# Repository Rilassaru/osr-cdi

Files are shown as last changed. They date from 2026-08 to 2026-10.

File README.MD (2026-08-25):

# OSR-CDI

Open-source programmable CDI (Capacitor Discharge Ignition) unit design and source repository for single-cylinder 2-stroke / 4-stroke motorcycles.

This repository includes complete design files for KiCad PCB layouts, PIC microcontroller firmware (MPLAB X), Windows-based map configuration utility "WinCDI" (Visual Studio), and baseline ignition map datasets.

---

## Directory Structure

```text
OSR-CDI/
|-- circuit/             # KiCad schematics, PCB layout, and manufacturing files (JLCPCB)
|   |-- KiCad_pcba/      # Main PCB board design and custom footprint library
|   `-- ...              # Variant circuits and legacy hardware designs
|-- firmware/            # PIC MCU firmware source code (MPLAB X IDE)
|-- wincdi/              # WinCDI map editing software source code (Visual Studio)
|   `-- lib/             # Pre-built static libraries and dependencies (FLTK, HIDAPI)
|-- genuine-map-files/   # Baseline and custom ignition curve maps (.bin / .hex / .csv)
`-- README.md

===========================================
Requirements & Toolchain
===========================================
   Circuit Design
      Tool: KiCad ver.10
      Notes: Custom footprints included in OSR-CDI_footprints.pretty

   Firmware
      Tool: MPLAB X IDE ver.6.2 & XC8 ver.2.5 Compiler
      Notes: Targets PIC16F1455 series microcontrollers

   Flashing / Debugging
      Tool: PICkit 3 / 4, MPLAB SNAP, MPLAB IPE
      Notes: Via on-board ICSP header pins

   GUI Utility (WinCDI)
      Tool: Visual Studio ver.2026 (C++ Desktop Development)
      Notes: Statically links against pre-built libraries in wincdi/lib/

===========================================
Getting Started
===========================================
1. Hardware Fabrication
   Ordering PCBs (e.g., JLCPCB):
      Production-ready Gerber ZIP archives, BOM (Bill of Materials) CSV files, and CPL placement CSV files are located in the circuit/KiCad_pcba/jlcpcb/ directory.

   Editing Schematics / Layout:
      Open the KiCad project files inside circuit/KiCad_pcba/. All custom footprints are bundled using relative paths.

2. Firmware Build & Flash
   1.Open the project under firmware/ using MPLAB X IDE.
   2.Select your target device (e.g., PIC16F1455) and XC8 compiler version, then run Clean and Build.
   3.Connect your programmer (PICkit / SNAP) to the ICSP header on the board and click Make and Program Device.

3. Building WinCDI (Windows Utility)
   1.Open the solution file (.sln) inside the wincdi/ directory with Visual Studio.
   2.Set configuration to Release (or Debug) and run Build Solution.
      Note: Required third-party libraries (FLTK, HIDAPI) are pre-configured in wincdi/lib/ for static linkage.

===========================================
Releases & Pre-built Packages
===========================================
If you only need ready-to-use binaries (WinCDI installers, compiled .hex firmware, and Gerber fabrication files), navigate to the [Releases] section on the right side of this repository.

===========================================
Disclaimer
===========================================
   Use this project, firmware, circuit schematics, and ignition map data entirely at your own risk.

   The authors, developers, and contributors assume no liability for any engine failure, vehicle damage, physical injury, electrical hazard, or any other damages resulting from the use of these materials.

   CDI circuits handle lethal high voltages and incorrect ignition timing can easily cause severe engine damage. Handle with care.

===========================================
License
===========================================
Project License
The core OSR-CDI design, firmware, and WinCDI utility code are released under the BSD 3-Clause License:

Copyright (c) OSR-CDI Project Contributors.
All rights reserved.

Redistribution and use in source and binary forms, with or without
modification, are permitted provided that the following conditions are met:

1. Redistributions of source code must retain the above copyright notice,
   this list of conditions and the following disclaimer.
2. Redistributions in binary form must reproduce the above copyright notice,
   this list of conditions and the following disclaimer in the documentation
   and/or other materials provided with the distribution.
3. Neither the name of the copyright holder nor the names of its
   contributors may be used to endorse or promote products derived from
   this software without specific prior written permission.

THIS SOFTWARE AND HARDWARE DESIGNS ARE PROVIDED BY THE COPYRIGHT HOLDERS AND
CONTRIBUTORS "AS IS" AND ANY EXPRESS OR IMPLIED WARRANTIES, INCLUDING, BUT NOT
LIMITED TO, THE IMPLIED WARRANTIES OF MERCHANTABILITY AND FITNESS FOR A
PARTICULAR PURPOSE ARE DISCLAIMED. IN NO EVENT SHALL THE COPYRIGHT HOLDER OR
CONTRIBUTORS BE LIABLE FOR ANY DIRECT, INDIRECT, INCIDENTAL, SPECIAL,
EXEMPLARY, OR CONSEQUENTIAL DAMAGES (INCLUDING, BUT NOT LIMITED TO,
PROCUREMENT OF SUBSTITUTE GOODS OR SERVICES; LOSS OF USE, DATA, OR PROFITS;
OR BUSINESS INTERRUPTION) HOWEVER CAUSED AND ON ANY THEORY OF LIABILITY,
WHETHER IN CONTRACT, STRICT LIABILITY, OR TORT (INCLUDING NEGLIGENCE OR
OTHERWISE) ARISING IN ANY WAY OUT OF THE USE OF THIS SOFTWARE, EVEN IF
ADVISED OF THE POSSIBILITY OF SUCH DAMAGE.

===========================================
Third-Party Libraries & Notices
===========================================
The wincdi/lib/ directory contains external binary dependencies used for building WinCDI. All rights belong to their respective copyright holders:

   FLTK (Fast Light Toolkit)
      License: GNU Library General Public License (LGPL) v2.0 with the FLTK Library Exception
      Website: https://www.fltk.org/
      The FLTK Library Exception explicitly permits static linking with applications without requiring the host application source code to be licensed under the LGPL.

   HIDAPI
      License: Multi-licensed (BSD-3-Clause / GPL v3 / HIDAPI License)
      Website: https://github.com/libusb/hidapi
   
   libpng / zlib / libjpeg
      License: zlib/libpng License / Independent JPEG Group License
      Included as static dependencies bundled with FLTK image routines.
   
   Microsoft Visual C++ 2010 Redistributable Component (msvcr100.dll)
      License: Microsoft Software License Terms

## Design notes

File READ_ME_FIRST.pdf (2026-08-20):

Please read first.

There is no warranty for all files, documents, and contents stated about the OSR - CDI you downloaded. No one will guarantee you at all.
There is no need to deal with everything at your own risk.
Only those who can correct mistakes themselves and return them to the community can use this file.
If you do not agree with this, you must immediately delete the downloaded file so that it does not invol ve anything at all.

はじめに必ずお読みください。

あなたがダウンロードしたOSR-CDIに関する全てのファイル、ドキュメント、記載した内容については一切の保証が ありません。
誰もあなたに一切保証してくれません。
全て自己責任で取り扱う必要がありません。
間違いはあなた自身が修正し、コミュニティに還元できる人だけが、このファイルを利用する事が出来ます。 これに同意できない人は、直ちにダウンロードしたファイルを削除して、今後一切関わらない様にしなければなりま せん。

请先阅读

所有关于您下载的OSR - CDI的所有文件，文档和内容均不作任何保证。 没有人会保证你的。
没有必要处理一切风险自负。
只有那些可以纠正错误并将其返回社区的人才可以使用此文件。 如果您不同意这一点，您必须立即删除下载的文件，使其完全不涉及任何内容。

처 음 에 반 드 시 읽 어 보 시 기 바 랍 니 다 .

당 신 이 다 운 로 드 한 OSR-CDI에 관 한 모 든 파 일 , 문 서 , 기 재 내 용 에 대 해 어 떠 한 보 증 도 하 지 않 습 니 다 . 아 무 도 당 신 에 게 보 증 해 주 지 않 습 니 다 .
모 두 자 기 책 임 으 로 취 급 할 필 요 가 없 습 니 다 .
실 수 는 자 신 이 수 정 하 고 지 역 사 회 에 환 원 할 수 있 는 사 람 만 이 이 파 일 을 사 용 할 수 있 습 니 다 .
이 에 동 의 하 지 않 는 사 람 은 즉 시 다 운 로 드 한 파 일 을 삭 제 하 고 향 후 일 절 관 계 않 도 록 해 야 합 니 다 .

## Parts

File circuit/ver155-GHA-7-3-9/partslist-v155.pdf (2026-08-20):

This is a reference only. Please select parts partly at your own risk. | 2026/2/8
OSR-CDI | Version1.5.x | * = common
Parts | Spec. | for | Pcs. | Comment | URL
PCB | Elecrow PCB | * | 1 | upload zip file to elecrow | https://www.elecrow.com/
PIC | PIC16F1455-I/P | * | 1 | PDIP | https://akizukidenshi.com/catalog/g/gI-10887/
Resist | 120 | * | 1 | carbon1/4W | https://akizukidenshi.com/catalog/g/g125121/
| 330 | * | 1 | carbon1/4W | https://akizukidenshi.com/catalog/g/gR-25331/
| 820 | * | 2 | carbon1/4W | https://akizukidenshi.com/catalog/g/gR-25821/
| 1.2K | * | 1 | carbon1/4W | https://akizukidenshi.com/catalog/g/gR-25122/
| 10K | * | 2 | carbon1/4W | https://akizukidenshi.com/catalog/g/gR-25103/
Cap. | 0.01uF50V | * | 2 | Ceramic capacitor 2.54pitch | https://akizukidenshi.com/catalog/g/gP-04063/
| 0.1uF50V | * | 3 | Ceramic capacitor 2.54pitch | https://akizukidenshi.com/catalog/g/gP-04065/
| 1uF50V | * | 3 | Ceramic capacitor 2.54pitch | https://akizukidenshi.com/catalog/g/gP-04066/
| 33uF50V | * | 2 | Electrolytic capacitor | https://www.sengoku.co.jp/mod/sgk_cart/detail.php?code=EEHD-0C3R
CDI cap. | 1.5uF400V | SDR200/DT200xx | 1 | UD40Y155K Film capacitor DC400V 1.5uF | https://www.sun-elle.com/eshopdo/refer/vid4009_42020.html
CDI cap. | 2.2uF400V | R1-Z/RZR/TZR | 1 | UD40Y225K Film capacitor DC400V 2.2uF | https://www.sun-elle.com/eshopdo/refer/vid4009_42030.html
CDI cap. | 1.5uF400V | RZV500R | 3 | UD40Y155K Film capacitor DC400V 1.5uF | https://www.sun-elle.com/eshopdo/refer/vid4009_42020.html
Diode | SD103A | * | 6 | Schottky diode for signal | https://akizukidenshi.com/catalog/g/gI-04271/
| UF2010 | R1-Z/RZR/RZV | 6 | Ultrafast Switching Rectifier | https://akizukidenshi.com/catalog/g/gI-00124/
| UF2010 | SDR200 | 7 | Ultrafast Switching Rectifier | https://akizukidenshi.com/catalog/g/gI-00124/
IC | 7805 regulator | * | 1 | Positive voltage regulator 100mA | https://akizukidenshi.com/catalog/g/gI-08973/
| DTC123EL | * | 1 | NPN Transistor with resistor | https://akizukidenshi.com/catalog/g/gI-12468/
| DTA123EL | * | 1 | PNP Transistor with resistor | https://akizukidenshi.com/catalog/g/gI-12465/
| TB6643KQ | * | 1 | Motor driver | https://akizukidenshi.com/catalog/g/gI-07688/
| 8P4SMA | * | 1 | Thyristor 400V 8A | https://akizukidenshi.com/catalog/g/gI-05001/
| TLP785 | * | 2 | photo coupler | https://akizukidenshi.com/catalog/g/gI-09846/
| | | | *TLP785 If you don't have any of the above, this is fine too | https://akizukidenshi.com/catalog/g/g107553/
| | | | *TLP785 If you don't have any of the above, this is fine too | https://akizukidenshi.com/catalog/g/g107554/
Others | Pin header | * | 1 | 40pin (use 5pin for PIC ICSP) | https://akizukidenshi.com/catalog/g/gC-00167/
| IC socket | * | 1 | 14pin | https://akizukidenshi.com/catalog/g/gP-00006/
| USB connector | * | 1 | miniB type female | https://akizukidenshi.com/catalog/g/gC-02235/
| Switch | * | 1 | on-off type | https://akizukidenshi.com/catalog/g/gP-03774/
| Tapping bis(3x5) | * | 1 | | https://akizukidenshi.com/catalog/g/gP-10254/
| Case | * | 1 | TAKACHI GHA7-3-9PB | https://www.sengoku.co.jp/mod/sgk_cart/detail.php?code=EEHD-0AL3
Cable | AVS-F 0.75sq x1m | SDR200 | 1 | Orange(橙)
| AVS-F 0.75sq x1m | SDR200 | 1 | White/Green(白/緑)
| AVS-F 0.75sq x1m | SDR200 | 1 | White/Black(白/黒)
| AVS-F 0.75sq x1m | SDR200 | 1 | Brown/Black(茶/黒)
| AVS-F 0.75sq x1m | SDR200 | 1 | Black/White(黒/白)
| AVS-F 0.75sq x1m | SDR200 | 1 | Yellow/Blue(黄/青)
| AVS-F 0.75sq x1m | SDR200 | 1 | Yellow(黄)
| AVS-F 0.75sq x1m | SDR200 | 1 | White/Red(白/赤)
| AVS-F 0.75sq x1m | SDR200 | 1 | Red/White(赤/白)
| AVS-F 0.75sq x1m | SDR200 | 2 | Black/Red(黒/赤)
| AVS-F 0.75sq x1m | SDR200 | 2 | Black(黒)
| AVS-F 0.75sq x1m | SDR200 | 1 | Brown(茶)
Cable | AVS-F 0.75sq x1m | R1-Z/RZR/RZV | 1 | Orange(橙)
| AVS-F 0.75sq x1m | R1-Z/RZR/RZV | 1 | White/Green(白/緑)
| AVS-F 0.75sq x1m | R1-Z/RZR/RZV | 1 | White/Black(白/黒)
| AVS-F 0.75sq x1m | R1-Z/RZR/RZV | 1 | Brown/Black(茶/黒)
| AVS-F 0.75sq x1m | R1-Z/RZR/RZV | 1 | Black/White(黒/白)
| AVS-F 0.75sq x1m | R1-Z/RZR/RZV | 1 | Yellow/Blue(黄/青)
| AVS-F 0.75sq x1m | R1-Z/RZR/RZV | 1 | Red/White(赤/白)
| AVS-F 0.75sq x1m | R1-Z/RZR/RZV | 1 | White/Red(白/赤)
| AVS-F 0.75sq x1m | R1-Z/RZR/RZV | 1 | Black/Red(黒/赤)
| AVS-F 0.75sq x1m | R1-Z/RZR/RZV | 1 | Red(赤)
| AVS-F 0.75sq x1m | R1-Z/RZR/RZV | 1 | Green(緑)
| AVS-F 0.75sq x1m | R1-Z/RZR/RZV | 2 | Black(黒)
| AVS-F 0.75sq x1m | R1-Z/RZR/RZV | 2 | Brown(茶)
Coupler | Coupler YPVS | R1-Z | 1 | 4P250 M | https://hi-1000.shop-pro.jp/ (http://hi-1000.shop-pro.jp/?pid=16134158)
| Coupler YPVS | R1-Z | 1 | 2P250 F | https://hi-1000.shop-pro.jp/ (http://hi-1000.shop-pro.jp/?pid=16134133)
| Coupler Pickup | R1-Z | 1 | 2極YPC防水M側コネクタ | https://hi-1000.shop-pro.jp/ (http://hi-1000.shop-pro.jp/?pid=26509217)
| Coupler others | R1-Z | 1 | 3極YPC防水F側コネクタ | https://hi-1000.shop-pro.jp/ (http://hi-1000.shop-pro.jp/?pid=26509264)
| Coupler Exciter | R1-Z | 1 | 3P110型オス端子側コネクタ | https://hi-1000.shop-pro.jp/ (http://hi-1000.shop-pro.jp/?pid=16046373)
| Coupler 2P110MRed | R1-Z | 1 | 2P110 M Red (for map switch) | https://hi-1000.shop-pro.jp/ (http://hi-1000.shop-pro.jp/?pid=86135216)
| Coupler 2P110FRed | R1-Z | 1 | 2P110 F Red (For map switch) | https://hi-1000.shop-pro.jp/ (http://hi-1000.shop-pro.jp/?pid=83037037)
Coupler | Coupler YPVS | RZR(29L) | 1 | 6P250 M | https://hi-1000.shop-pro.jp/ (http://hi-1000.shop-pro.jp/?pid=16134172)
| Coupler YPVS | RZR(29L) | 1 | 3P250 M | https://hi-1000.shop-pro.jp/ (http://hi-1000.shop-pro.jp/?pid=16134146)
| Coupler Pickup | RZR(29L) | 1 | YPC 2P M | https://hi-1000.shop-pro.jp/ (http://hi-1000.shop-pro.jp/?pid=48426715)
| Coupler others | RZR(29L) | 1 | YPC 4P F | https://hi-1000.shop-pro.jp/ (http://hi-1000.shop-pro.jp/?pid=56921534)
| Coupler Exciter | RZR(29L) | 1 | YPC 3P M | https://hi-1000.shop-pro.jp/ (http://hi-1000.shop-pro.jp/?pid=61793933)
| Coupler 2P110MRed | RZR(29L) | 1 | 2P110 M Red (for map switch) | https://hi-1000.shop-pro.jp/ (http://hi-1000.shop-pro.jp/?pid=86135216)
| Coupler 2P110FRed | RZR(29L) | 1 | 2P110 F Red (For map switch) | https://hi-1000.shop-pro.jp/ (http://hi-1000.shop-pro.jp/?pid=83037037)
Coupler | Coupler YPVS | RZV500R | 1 | YPC防水M8
| Coupler CDI | RZV500R | 1 | YPC防水F9
| Coupler 2P110MRed | RZV500R | 1 | 2P110 M Red (for map switch) | https://hi-1000.shop-pro.jp/ (http://hi-1000.shop-pro.jp/?pid=86135216)
| Coupler 2P110FRed | RZV500R | 1 | 2P110 F Red (For map switch) | https://hi-1000.shop-pro.jp/ (http://hi-1000.shop-pro.jp/?pid=83037037)
Grommet | NG-79-G | * | 1 | | https://www.monotaro.com/p/0933/3895/

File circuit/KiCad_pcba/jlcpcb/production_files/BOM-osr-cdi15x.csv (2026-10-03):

Comment | Designator | Footprint | LCSC | Quantity
1.2K | R2,R3,R5 | R_0603_1608Metric | C22765 | 3
100nF | C1,C10,C13,C14,C2,C3,C9 | C_0603_1608Metric | C14663 | 7
10K | R1,R9 | R_0603_1608Metric | C25804 | 2
10nF | C11,C6 | C_0603_1608Metric | C57112 | 2
120 | R6 | R_0603_1608Metric | C22787 | 1
1uF | C4,C7 | C_0603_1608Metric | C15849 | 2
330 | R13 | R_0603_1608Metric | C23138 | 1
330R(1/4W) | R10 | R_1206_3216Metric | C2907482 | 1
33uF | C5,C8 | CAP-SMD_BD6.3-L6.6-W6.6-FD-1 | C240518 | 2
470 | R4 | R_0603_1608Metric | C23179 | 1
5.1K | R7,R8 | R_0603_1608Metric | C23186 | 2
820R(1/4W) | R11,R12 | R_1206_3216Metric | C2974057 | 2
BT151 | Q2 | TO-252-2_L6.6-W6.1-P4.57-LS10.1-BR-CW | C2900856 | 1
CJ7805 | LDO1 | TO-252-2_L6.6-W6.1-P4.58-LS10.1-BR-CW | C21706 | 1
DTA123 | Q4 | SOT-23-3_L2.9-W1.3-P1.90-LS2.4-BR | C426848 | 1
DTC123 | Q1,Q3 | SOT-23-3_L2.9-W1.3-P1.90-LS2.4-BR | C406040 | 2
HC-TYPE-C-16P-01A | U2 | USB-C-SMD_HC-TYPE-C-16P-01A | C2894897 | 1
KT-0603R | LED1 | LED-SMD_L1.6-W0.8-R-RD | C2286 | 1
PIC16F1455-I/SL | U1 | PIC16F1455-SOIC-14_L8.7-W3.9-P1.27-LS6.0-BL | C640946 | 1
SD103AW | D1,D2,D3,D4,D5,D6 | SD103AW_SOD-123_L2.8-W1.8-LS3.7-RD | C181204 | 6
SS34_C8678 | D12 | SS34_SMA_L4.3-W2.6-LS5.2-RD | C8678 | 1
TB67H450FNG,EL | U5 | HSOP-8_L5.0-W4.0-P1.27-LS6.2-BL-EP | C545417 | 1
TLP785BL | U3,U4 | SOP-4_L6.5-W4.6-P2.54-LS10.0 | C2848507 | 2
US2M | D10,D11,D13,D7,D8,D9 | US2M_SMA_L4.4-W2.8-LS5.4-RD | C64958 | 6

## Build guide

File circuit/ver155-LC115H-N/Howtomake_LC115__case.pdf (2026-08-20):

おもて面で、最低限必要な実装範囲はこの赤枠の部分です

うら面で、最低限必要な実装範囲はこの赤枠の部分です

SDRのみ必要です

5

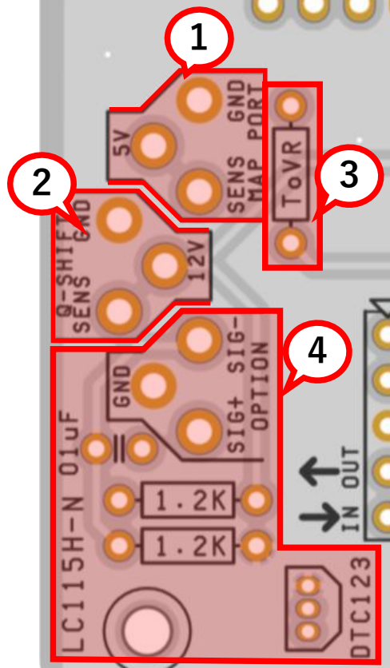
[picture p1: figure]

① マップ切り替えが必要な場合に必要
② クイックシフターを使う場合に必要
③ スロットルポジションセンサーを使う場合に必要
④ 点火シグナルを取り出す場合に必要
⑤ SDR用を制作する場合に必要

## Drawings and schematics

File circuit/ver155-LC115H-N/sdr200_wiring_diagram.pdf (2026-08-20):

## YAMAHA SDR Wiring color diagram w/OSR-CDI

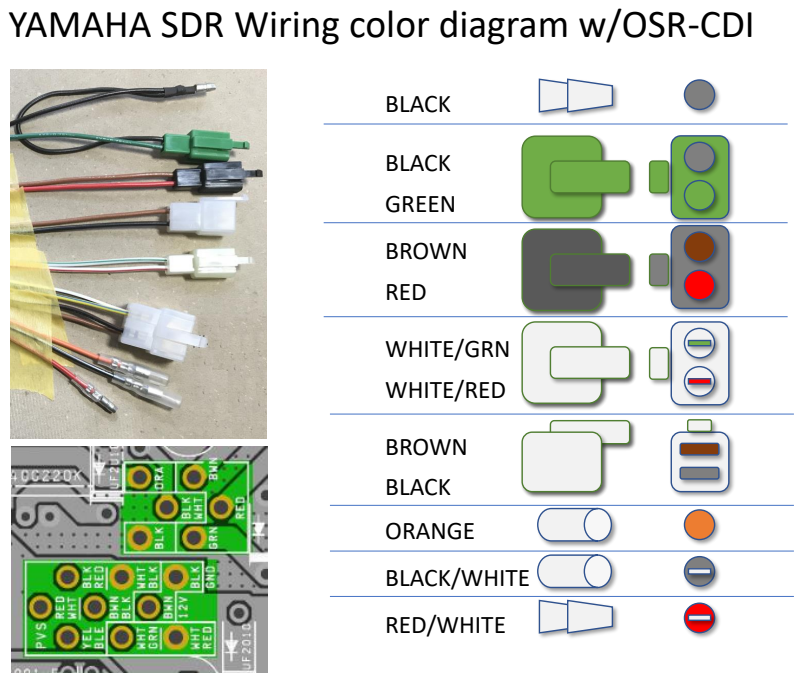
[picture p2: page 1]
BROWN; BLACK; WHITE/GRN; WHITE/RED; RED; GREEN; ORANGE; BLACK/WHITE; RED/WHITE

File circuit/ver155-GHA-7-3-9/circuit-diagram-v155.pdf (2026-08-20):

OSR CDIv1.5.5 2026/02/08 Rilassaru + Mass.Matt.

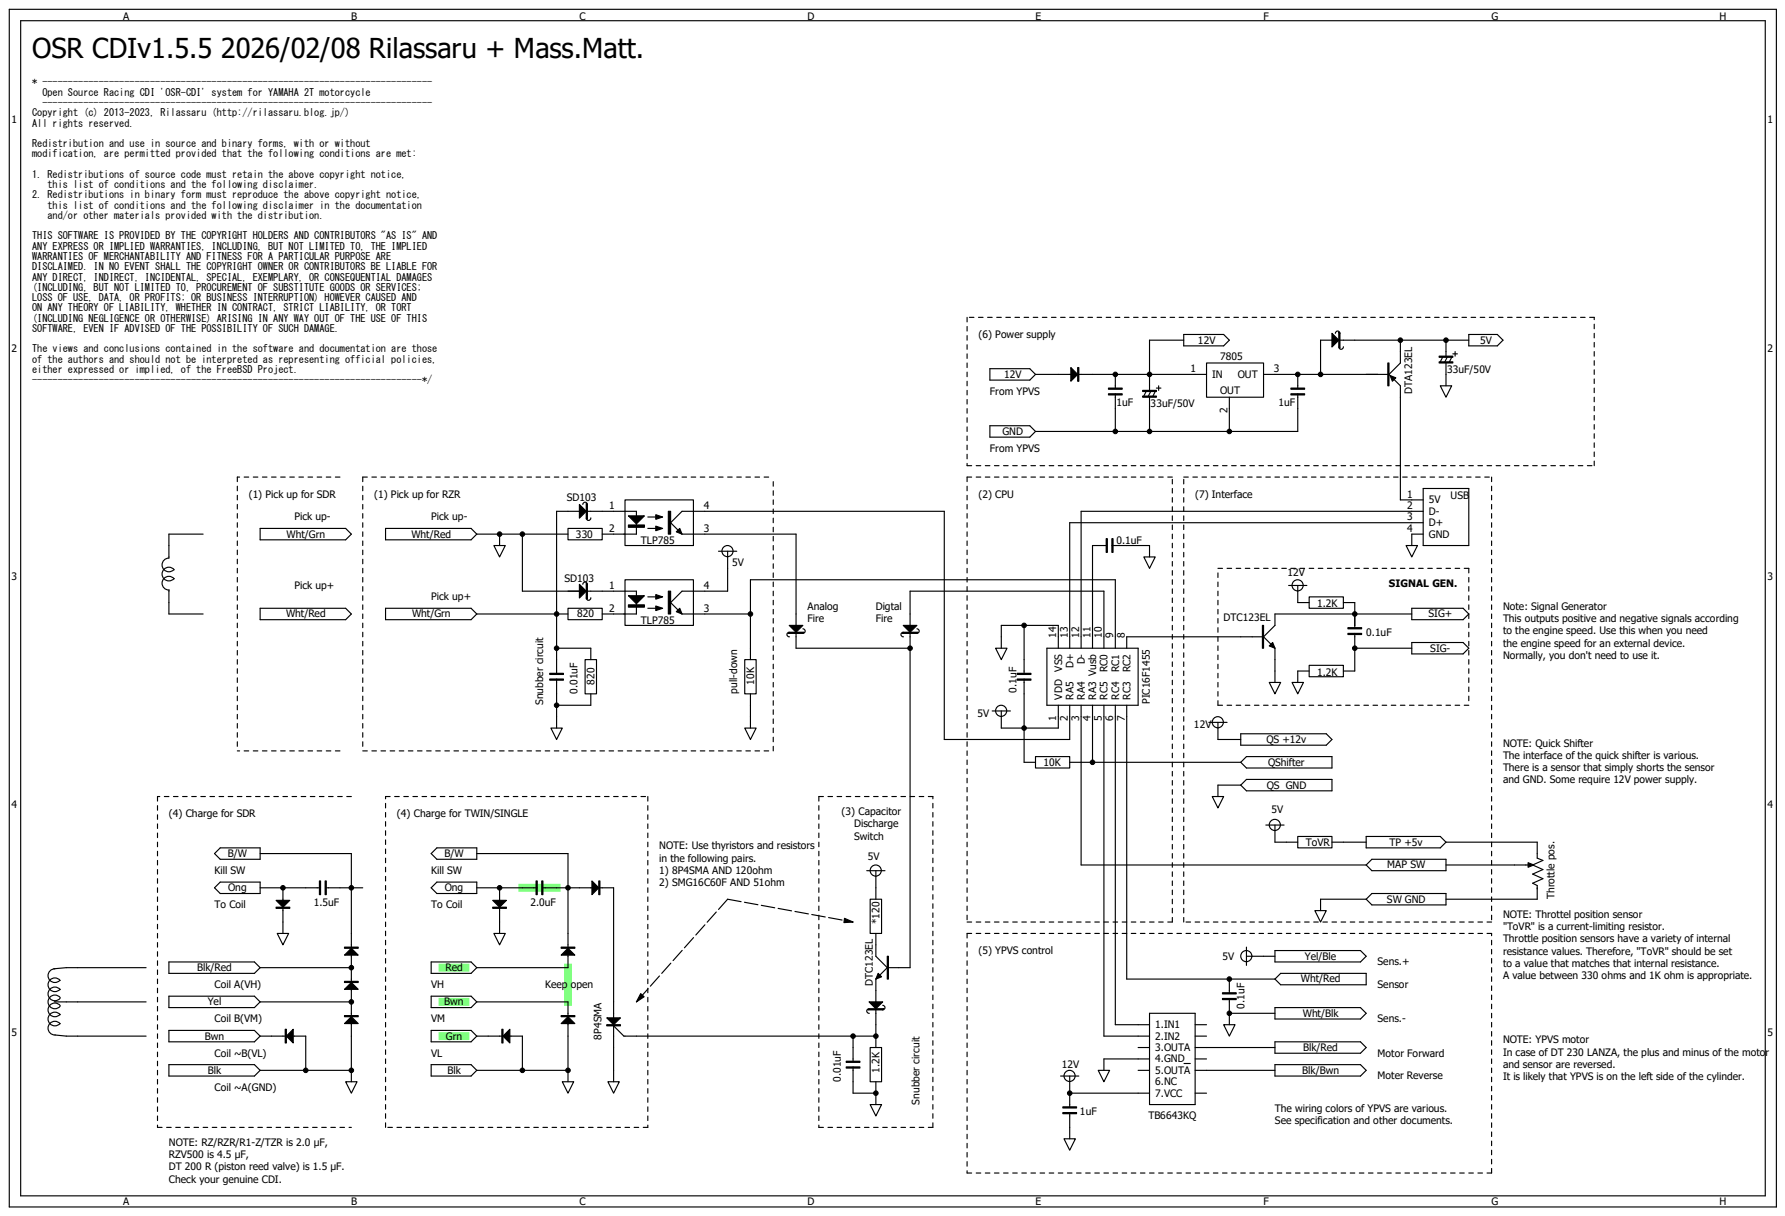
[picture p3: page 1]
(3) Capacitor Discharge Switch; Analog Fire; Digtal Fire; SIGNAL GEN.; TLP785; 12V VDD; 1 VSS 14 RC4; 5 Vusb 11 RA3; 4 D+ 13 D- 12 PIC16F1455; 1.IN1 2.IN2 3.OUTA 4.GND; 7.VCC; 5.OUTA; 5V ⁸²⁰; Throttle pos.; ToVR 0.1uF 0.1uF; DTC123EL; OUT; DTA¹²³EL; 33uF/50V 8P4SMA; Pick up-; Pick up+; Wht/Red; Wht/Grn; (1) Pick up for SDR; (1) Pick up for RZR; From YPVS; GND; QShifter; Blk/Bwn; Blk/Red; Yel/Ble; Sensor; Sens.-; Sens.+; Wht/Blk; Motor Forward; Moter Reverse; QS GND; Kill SW; To Coil; Ong; Grn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

Open Source Racing CDI 'OSR-CDI' system for YAMAHA 2T motorcycle
Copyright (c) 2013-2023, Rilassaru (http://rilassaru.blog.jp/)
All rights reserved.

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

1. Redistributions of source code must retain the above copyright notice,
this list of conditions and the following disclaimer.
2. Redistributions in binary form must reproduce the above copyright notice,
this list of conditions and the following disclaimer in the documentation
and/or other materials provided with the distribution.

THIS SOFTWARE IS PROVIDED BY THE COPYRIGHT HOLDERS AND CONTRIBUTORS "AS IS" AND
ANY EXPRESS OR IMPLIED WARRANTIES, INCLUDING, BUT NOT LIMITED TO, THE IMPLIED
WARRANTIES OF MERCHANTABILITY AND FITNESS FOR A PARTICULAR PURPOSE ARE
DISCLAIMED. IN NO EVENT SHALL THE COPYRIGHT OWNER OR CONTRIBUTORS BE LIABLE FOR
ANY DIRECT, INDIRECT, INCIDENTAL, SPECIAL, EXEMPLARY, OR CONSEQUENTIAL DAMAGES
(INCLUDING, BUT NOT LIMITED TO, PROCUREMENT OF SUBSTITUTE GOODS OR SERVICES;
LOSS OF USE, DATA, OR PROFITS; OR BUSINESS INTERRUPTION) HOWEVER CAUSED AND
ON ANY THEORY OF LIABILITY, WHETHER IN CONTRACT, STRICT LIABILITY, OR TORT
(INCLUDING NEGLIGENCE OR OTHERWISE) ARISING IN ANY WAY OUT OF THE USE OF THIS
SOFTWARE, EVEN IF ADVISED OF THE POSSIBILITY OF SUCH DAMAGE.
The views and conclusions contained in the software and documentation are those
of the authors and should not be interpreted as representing official policies,
either expressed or implied, of the FreeBSD Project.

USB Snubber circuit

D+ 3
GND 4

Note: Signal Generator
This outputs positive and negative signals according
to the engine speed. Use this when you need
the engine speed for an external device.
Normally, you don't need to use it.

MAP SW pull-down Snubber circuit

NOTE: Quick Shifter
The interface of the quick shifter is various.
There is a sensor that simply shorts the sensor
and GND. Some require 12V power supply.

NOTE: Use thyristors and resistors
in the following pairs.
1) 8P4SMA AND 120ohm
2) SMG16C60F AND 51ohm

NOTE: Throttel position sensor
"ToVR" is a current-limiting resistor.
Throttle position sensors have a variety of internal
resistance values. Therefore, "ToVR" should be set
to a value that matches that internal resistance.
A value between 330 ohms and 1K ohm is appropriate.

NOTE: YPVS motor
In case of DT 230 LANZA, the plus and minus of the motor
and sensor are reversed.
It is likely that YPVS is on the left side of the cylinder.

The wiring colors of YPVS are various.
See specification and other documents.

NOTE: RZ/RZR/R1-Z/TZR is 2.0 μF,
RZV500 is 4.5 μF,
DT 200 R (piston reed valve) is 1.5 μF.
Check your genuine CDI.

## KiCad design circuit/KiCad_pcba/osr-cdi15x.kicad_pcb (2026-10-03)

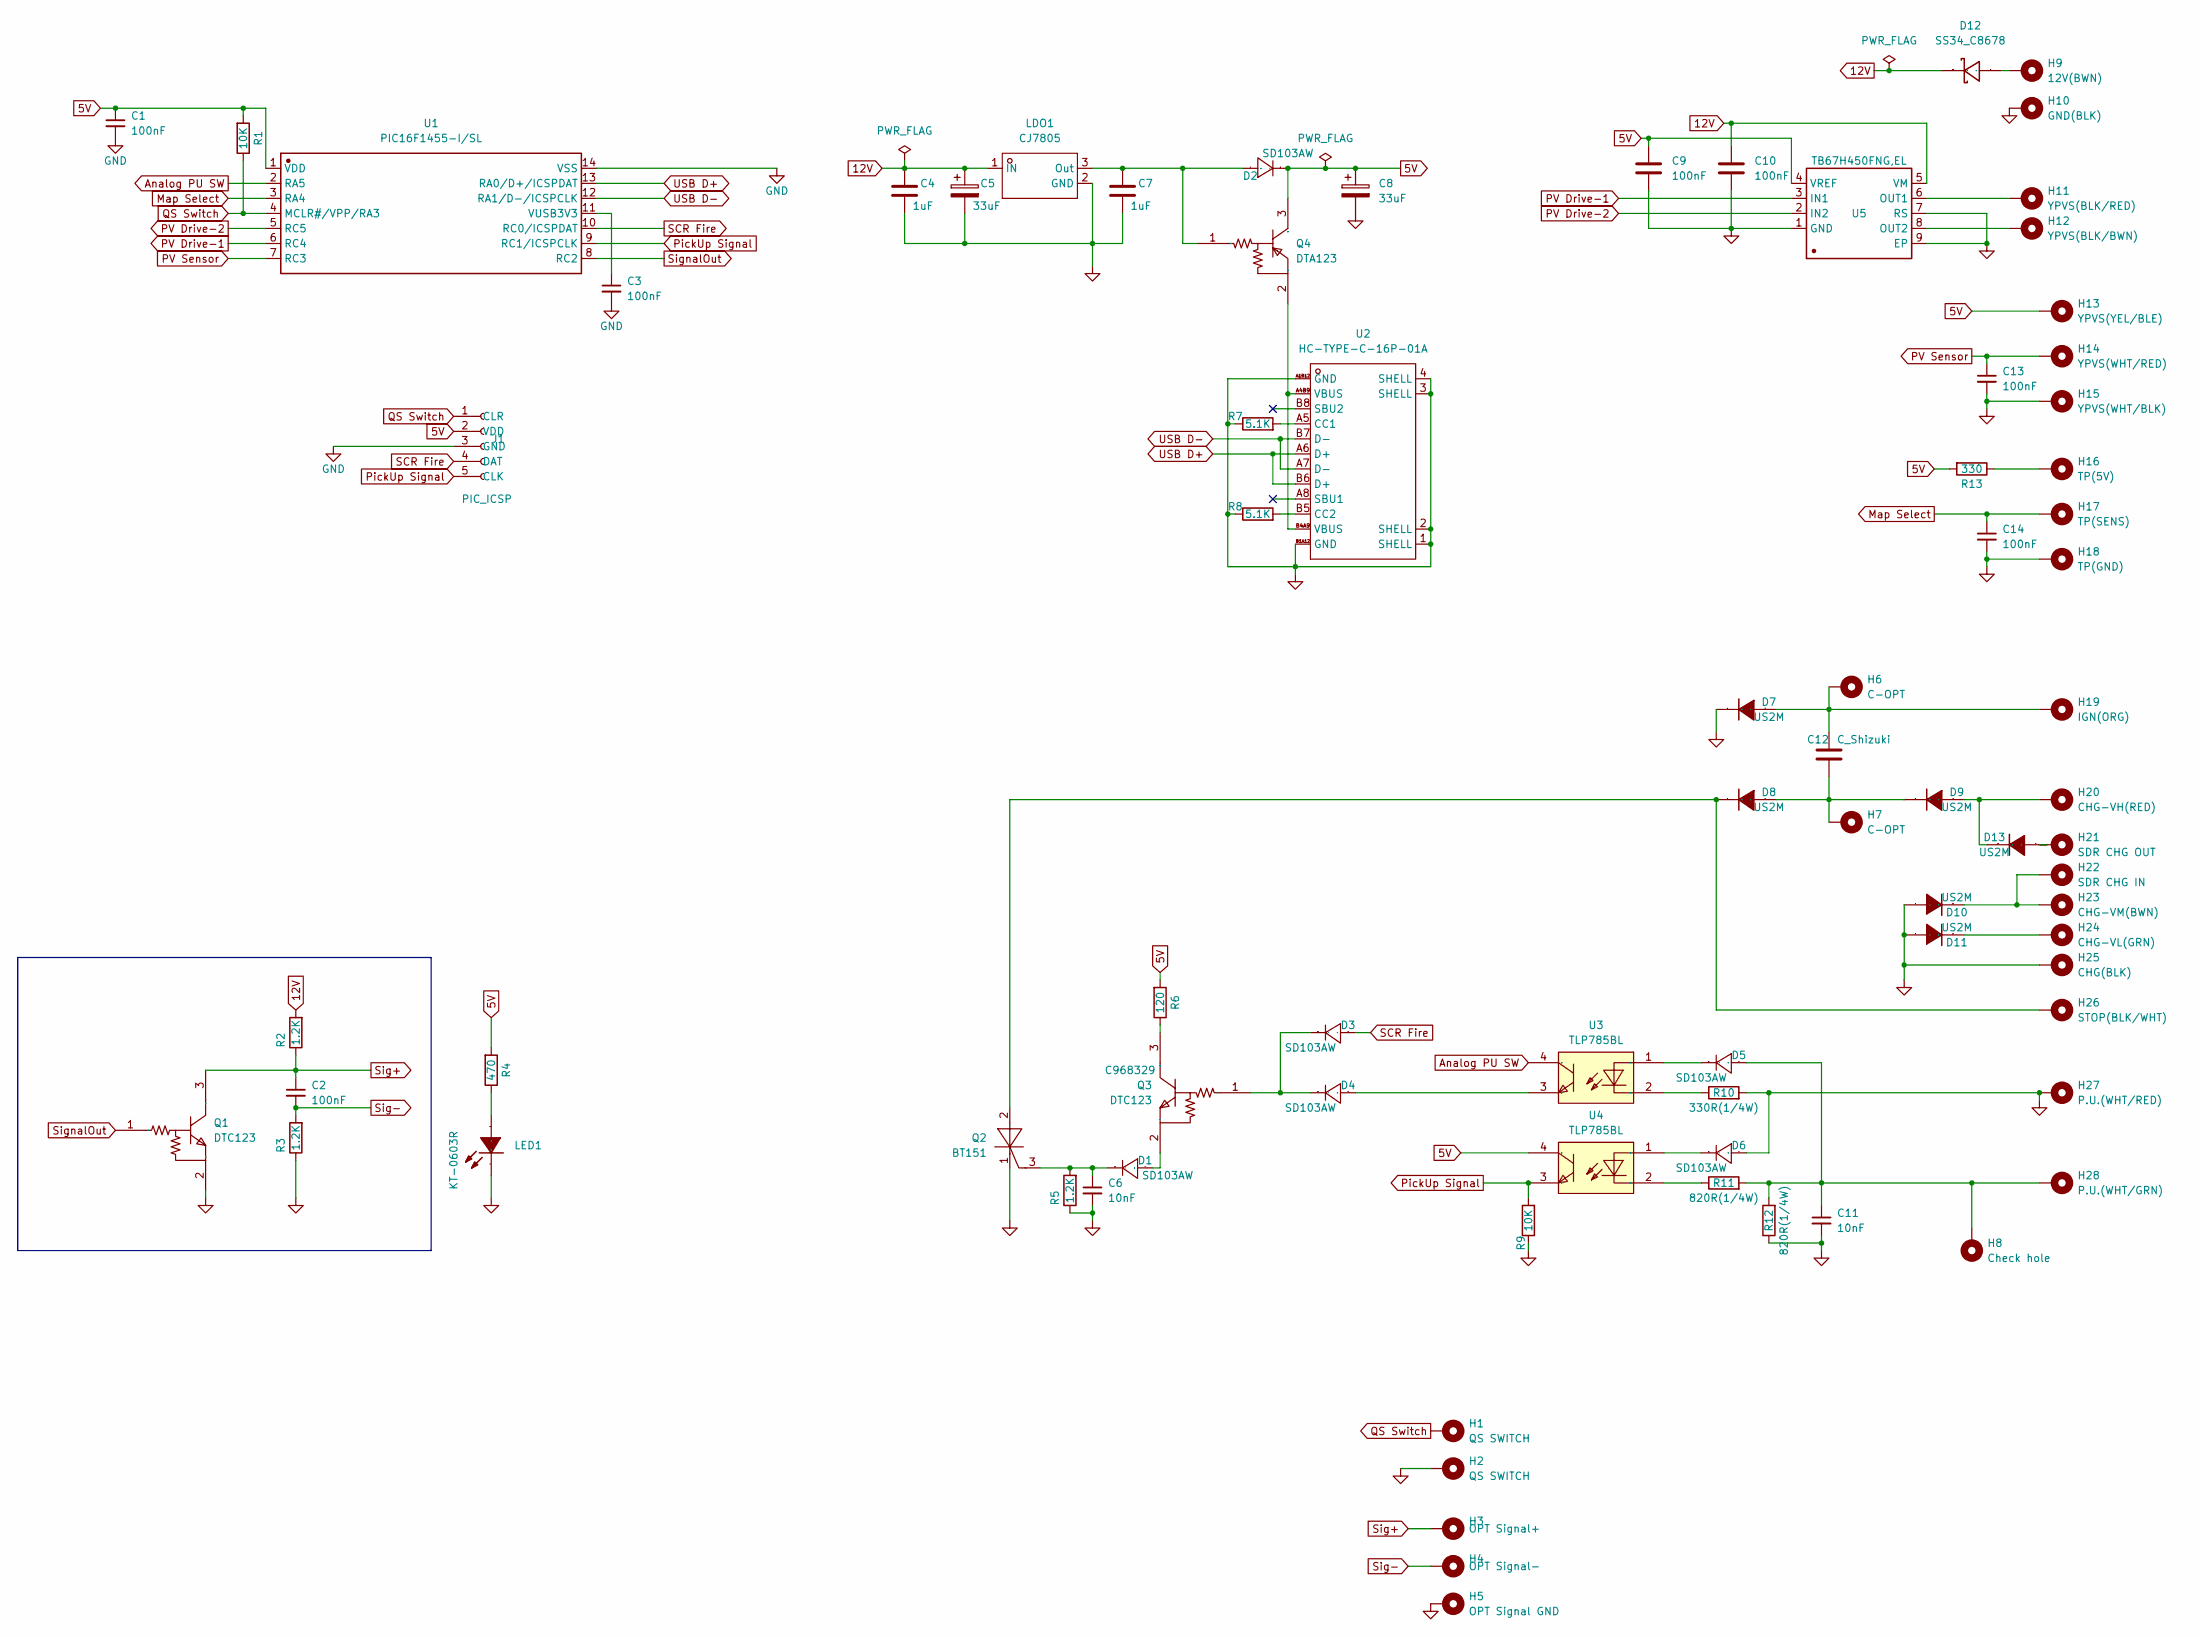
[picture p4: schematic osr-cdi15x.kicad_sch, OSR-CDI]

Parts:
C1, C2, C3, C9, C10, C13, C14: 100nF; C_0603_1608Metric
C4, C7: 1uF; C_0603_1608Metric
C5, C8: 33uF; CAP-SMD_BD6.3-L6.6-W6.6-FD-1
C6, C11: 10nF; C_0603_1608Metric
C12: C_Shizuki; Capacitor_Sizuki400V
D1, D2, D3, D4, D5, D6: SD103AW; SD103AW_SOD-123_L2.8-W1.8-LS3.7-RD; JLC_3DModel_Q 560a7cf99d0e44cb9af362aaf5d7923d
D7, D8, D9, D10, D11, D13: US2M; US2M_SMA_L4.4-W2.8-LS5.4-RD; Manufacturer Part US2M
D12: SS34_C8678; SS34_SMA_L4.3-W2.6-LS5.2-RD; Manufacturer Part SS34
H1, H2: QS SWITCH; M_Hole_2.5mm_Pad_075Wire
H3: OPT Signal+; M_Hole_2.5mm_Pad_075Wire
H4: OPT Signal-; M_Hole_2.5mm_Pad_075Wire
H5: OPT Signal GND; M_Hole_2.5mm_Pad_075Wire
H6, H7: C-OPT; M_Hole_2.5mm_Pad_075Wire
H8: Check hole; M_Hole_1.6-0.9mm_Pad
H9: 12V(BWN); M_Hole_2.5mm_Pad_075Wire
H10: GND(BLK); M_Hole_2.5mm_Pad_075Wire
H11: YPVS(BLK/RED); M_Hole_2.5mm_Pad_075Wire
H12: YPVS(BLK/BWN); M_Hole_2.5mm_Pad_075Wire
H13: YPVS(YEL/BLE); M_Hole_2.5mm_Pad_075Wire
H14: YPVS(WHT/RED); M_Hole_2.5mm_Pad_075Wire
H15: YPVS(WHT/BLK); M_Hole_2.5mm_Pad_075Wire
H16: TP(5V); M_Hole_2.5mm_Pad_075Wire
H17: TP(SENS); M_Hole_2.5mm_Pad_075Wire
H18: TP(GND); M_Hole_2.5mm_Pad_075Wire
H19: IGN(ORG); M_Hole_2.5mm_Pad_075Wire
H20: CHG-VH(RED); M_Hole_2.5mm_Pad_075Wire
H21: SDR CHG OUT; M_SQ_Hole_2.5mm_Pad_075Wire
H22: SDR CHG IN; M_SQ_Hole_2.5mm_Pad_075Wire
H23: CHG-VM(BWN); M_Hole_2.5mm_Pad_075Wire
H24: CHG-VL(GRN); M_Hole_2.5mm_Pad_075Wire
H25: CHG(BLK); M_Hole_2.5mm_Pad_075Wire
H26: STOP(BLK/WHT); M_Hole_2.5mm_Pad_075Wire
H27: P.U.(WHT/RED); M_Hole_2.5mm_Pad_075Wire
H28: P.U.(WHT/GRN); M_Hole_2.5mm_Pad_075Wire
J1: PIC_ICSP; ICSP_5PIN
LDO1: CJ7805; TO-252-2_L6.6-W6.1-P4.58-LS10.1-BR-CW; Manufacturer Part CJ7805 3%; LCSC Part Name 5V 1.5A 35V
LED1: KT-0603R; LED-SMD_L1.6-W0.8-R-RD; Manufacturer Part KT-0603R
Q1, Q3: DTC123; SOT-23-3_L2.9-W1.3-P1.90-LS2.4-BR; Manufacturer Part DTC123JCA; LCSC Part Name 数字晶体管（内置电阻）
Q2: BT151; TO-252-2_L6.6-W6.1-P4.57-LS10.1-BR-CW; Manufacturer Part BT151; LCSC Part Name BT151
Q4: DTA123; SOT-23-3_L2.9-W1.3-P1.90-LS2.4-BR; Manufacturer Part DTA123JCA; LCSC Part Name 数字晶体管（内置电阻）
R1, R9: 10K; R_0603_1608Metric
R2, R3, R5: 1.2K; R_0603_1608Metric
R4: 470; R_0603_1608Metric
R6: 120; R_0603_1608Metric
R7, R8: 5.1K; R_0603_1608Metric
R10: 330R(1/4W); R_1206_3216Metric
R11, R12: 820R(1/4W); R_1206_3216Metric
R13: 330; R_0603_1608Metric
U1: PIC16F1455-I/SL; PIC16F1455-SOIC-14_L8.7-W3.9-P1.27-LS6.0-BL; Manufacturer Part PIC16F1455-I/SL
U2: HC-TYPE-C-16P-01A; USB-C-SMD_HC-TYPE-C-16P-01A; Manufacturer Part HC-TYPE-C-16P-01A; LCSC Part Name Type-C 母 卧贴
U3, U4: TLP785BL; SOP-4_L6.5-W4.6-P2.54-LS10.0; Manufacturer Part TLP785(BL-TP6,F; LCSC Part Name 光电耦合器，红外发光二极管与光电晶体管
U5: TB67H450FNG,EL; HSOP-8_L5.0-W4.0-P1.27-LS6.2-BL-EP; Manufacturer Part TB67H450FNG,EL

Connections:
5V: C1.1, C8.1, C9.1, D2.1 (C), H13.1 (1_1), J1.2 (VDD), Q4.3 (OUT), R1.2, R4.2, R6.2, R13.2, U1.1 (VDD), U4.4 (COL), U5.4 (VREF)
12V: C4.1, C5.1, C10.1, D12.1 (K), LDO1.1 (IN), R2.2, U5.5 (VM)
Analog PU SW: U1.2 (RA5), U3.4 (COL)
GND: C1.2, C3.2, C4.2, C5.2, C6.2, C7.2, C8.2, C9.2, C10.2, C11.2, C13.2, C14.2, D6.2 (A), D7.1 (K), D10.2 (A), D11.2 (A), H2.1 (1_1), H5.1 (1_1), H10.1 (1_1), H15.1 (1_1), H18.1 (1_1), H25.1 (1_1), H27.1 (1_1), J1.3 (GND), LDO1.2 (GND), LED1.2 (K), Q1.2 (GND), Q2.1 (K), R3.1, R5.1, R7.1, R8.1, R9.1, R10.2, R12.1, U1.14 (VSS), U2.1 (SHELL), U2.2 (SHELL), U2.3 (SHELL), U2.4 (SHELL), U2.A1B12 (GND), U2.B1A12 (GND), U5.1 (GND), U5.7 (RS), U5.9 (EP)
Map Select: C14.1, H17.1 (1_1), U1.3 (RA4)
unnamed: D1.2 (A), Q3.2 (GND)
unnamed: C6.1, D1.1 (C), Q2.3 (G), R5.2
unnamed: C7.1, D2.2 (A), LDO1.3 (Out), Q4.1 (IN)
unnamed: D3.1 (C), D4.1 (C), Q3.1 (IN)
unnamed: D4.2 (A), U3.3 (EMI)
unnamed: C11.1, D5.2 (A), H8.1 (1_1), H28.1 (1_1), R11.2, R12.2
unnamed: D5.1 (C), U3.1 (AN)
unnamed: D6.1 (C), U4.1 (AN)
unnamed: C12.2, D7.2 (A), H6.1 (1_1), H19.1 (1_1)
unnamed: C12.1, D8.2 (A), D9.1 (K), H7.1 (1_1)
unnamed: D8.1 (K), H26.1 (1_1), Q2.2 (A)
unnamed: D10.1 (K), H22.1 (1_1), H23.1 (1_1)
unnamed: D11.1 (K), H24.1 (1_1)
unnamed: D12.2 (A), H9.1 (1_1)
unnamed: D13.2 (A), H21.1 (1_1)
unnamed: D9.2 (A), D13.1 (K), H20.1 (1_1)
unnamed: H16.1 (1_1), R13.1
unnamed: LED1.1 (A), R4.1
unnamed: Q3.3 (OUT), R6.1
unnamed: Q4.2 (GND), U2.A4B9 (VBUS), U2.B4A9 (VBUS)
unnamed: C3.1, U1.11 (VUSB3V3)
unnamed: R7.2, U2.A5 (CC1)
unnamed: R8.2, U2.B5 (CC2)
unnamed: R10.1, U3.2 (CAT)
unnamed: R11.1, U4.2 (CAT)
unnamed: H11.1 (1_1), U5.6 (OUT1)
unnamed: H12.1 (1_1), U5.8 (OUT2)
PV Drive-1: U1.6 (RC4), U5.3 (IN1)
PV Drive-2: U1.5 (RC5), U5.2 (IN2)
PV Sensor: C13.1, H14.1 (1_1), U1.7 (RC3)
PickUp Signal: J1.5 (CLK), R9.2, U1.9 (RC1/ICSPCLK), U4.3 (EMI)
QS Switch: H1.1 (1_1), J1.1 (CLR), R1.1, U1.4 (MCLR#/VPP/RA3)
SCR Fire: D3.2 (A), J1.4 (DAT), U1.10 (RC0/ICSPDAT)
Sig+: C2.1, H3.1 (1_1), Q1.3 (OUT), R2.1
Sig-: C2.2, H4.1 (1_1), R3.2
SignalOut: Q1.1 (IN), U1.8 (RC2)
USB D+: U1.13 (RA0/D+/ICSPDAT), U2.A6 (D+), U2.B6 (D+)
USB D-: U1.12 (RA1/D-/ICSPCLK), U2.A7 (D-), U2.B7 (D-)

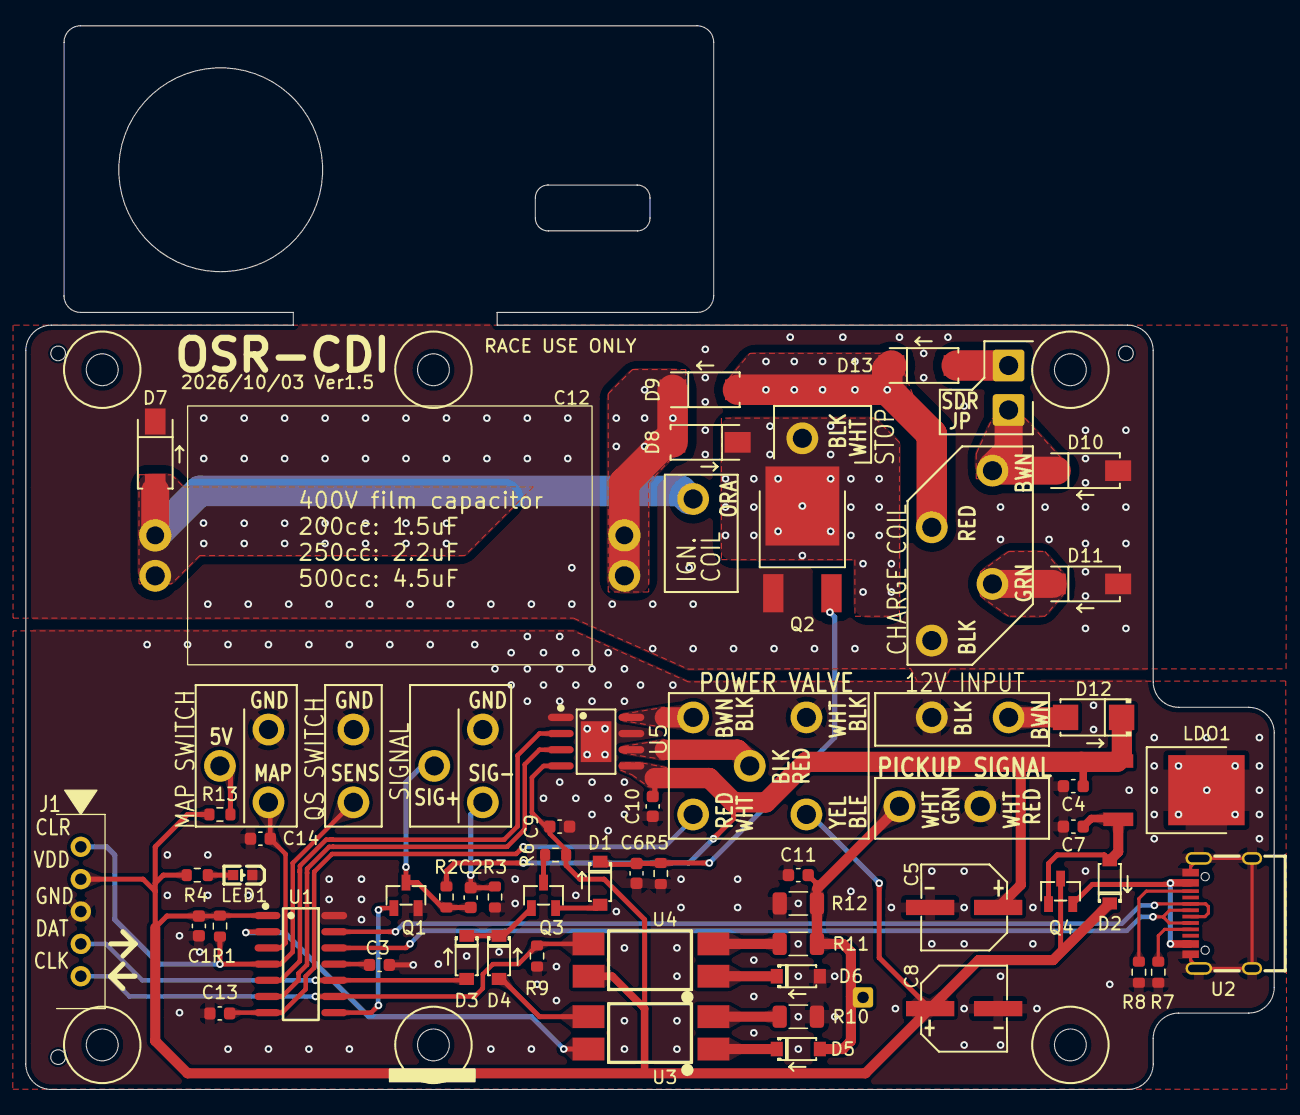
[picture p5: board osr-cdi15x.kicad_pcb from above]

Board: 2 copper layers, 98.0 x 83.5 mm, 80 parts (0 on the bottom side), 43 nets.

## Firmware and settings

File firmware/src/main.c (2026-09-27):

/* ----------------------------------------------------------------------------
  Open Source Replica CDI 'OSR-CDI' system for YAMAHA 2T motorcycle
  ----------------------------------------------------------------------------
Copyright(c) 2013-, Rilassaru(http://rilassaru.blog.jp/)
All rights reserved.

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
1. Redistributions of source code must retain the above copyright notice,
   this list of conditions and the following disclaimer. 
2. Redistributions in binary form must reproduce the above copyright notice,
   this list of conditions and the following disclaimer in the documentation
   and/or other materials provided with the distribution. 

THIS SOFTWARE IS PROVIDED BY THE COPYRIGHT HOLDERS AND CONTRIBUTORS "AS IS" AND
ANY EXPRESS OR IMPLIED WARRANTIES, INCLUDING, BUT NOT LIMITED TO, THE IMPLIED
WARRANTIES OF MERCHANTABILITY AND FITNESS FOR A PARTICULAR PURPOSE ARE
DISCLAIMED. IN NO EVENT SHALL THE COPYRIGHT OWNER OR CONTRIBUTORS BE LIABLE FOR
ANY DIRECT, INDIRECT, INCIDENTAL, SPECIAL, EXEMPLARY, OR CONSEQUENTIAL DAMAGES
(INCLUDING, BUT NOT LIMITED TO, PROCUREMENT OF SUBSTITUTE GOODS OR SERVICES;
LOSS OF USE, DATA, OR PROFITS; OR BUSINESS INTERRUPTION) HOWEVER CAUSED AND
ON ANY THEORY OF LIABILITY, WHETHER IN CONTRACT, STRICT LIABILITY, OR TORT
(INCLUDING NEGLIGENCE OR OTHERWISE) ARISING IN ANY WAY OUT OF THE USE OF THIS
SOFTWARE, EVEN IF ADVISED OF THE POSSIBILITY OF SUCH DAMAGE.

The views and conclusions contained in the software and documentation are those
of the authors and should not be interpreted as representing official policies, 
either expressed or implied, of the FreeBSD Project.
----------------------------------------------------------------------------*/
/* Updates
DATE        VERSION UPDATE
01/NOV/2015 2.2.0   RCDI PIC16F1455 version released.
10/OCT/2016 2.3.0a  Solenid driver added.
26/OCT/2016 2.3.0b  Rev limitter added.
18/FEB/2017 2.3.1   Release.
04/MAY/2017 2.3.2   For RZ250R(29L), Moved the division processing into timer2 routine.
04/JUN/2017 2.3.3   Fixed for both Single and Twin specification.
-----------------
-- A product named RCDI existed in the past, so the name was changed to OSR-CDI.
-----------------
08/AUG/2017 1.0.1   OSR-CDI version beta
01/JAN/2018 1.0.4   Minor bug fix, final release
-----------------
11/MAR/2018 1.1.0   2nd P.U. signal supplessed for DT200/TZR125/RZ125
15/APL/2018 1.1.1   2nd P.U. signal enabler for DT200/TZR125/RZ125
12/MAR/2018 1.1.2   Changeable PV value to fit DT230 LANZA
-----------------
16/JUN/2018 1.2.0   Fixed some bugs and final release
17/OCT/2019 1.2.1   Plus wave pick up singal enable timing was changed.
-----------------
05/JUN/2019 1.3.0   The control of INTF was changed in order to avoid the noise
                    at the time of spark.
15/AUG/2019 1.3.0b  Thyristor gate time changed.
-----------------
14/NOV/2020 1.4.0a  Extended the ignition refusal time using Timer0.
                    Changed the behavior of Quick Shifter. 
27/Feb/2021 1.4.0b  Suppresses ignition when the first positive wave arrives.
03/JUN/2022 1.4.0c  Fix do not stop with 'use quick shifter as stop switch'.
-----------------
06/JUN/2023 1.5.0   New version released. Supports 4 maps.
26/JUL/2023 1.5.1   Changed analog ignition mechanism.
                    Changed the scanning method for maximum and minimum values
                    in the initial operation of PVS.
25/JUL/2023 1.5.2   Analog ignition control has been revised to improve starting
                    performance.
27/JUL/2023         Fixed a bug in PV control associated with 4ch.
29/SEP/2024 1.5.3   Added option to maintain analog ignition below a certain rotation speed.
10/Feb/2025 1.5.4a  The on time of the thyristor gate is made variable.
03/Mar/2025 1.5.4b  When the analog ignition count is set to 0,
                    analog ignition is not actually performed.
08/Feb/2026 1.5.5   Minor bug-fix.
12/Aug/2026 1.5.6a  PVS Added a fully closed state to the initial operation of the PVS.
                    *The version has been updated to include a PCBA case for the circuit board assembly.
06/Oct/2026 1.5.6b  USB userinterface modified UserID/DevID/RevID
26/Oct/2026 1.5.6c  XC8 Ver. 4.0 (C99) compliance and source file modularization/organization
-----------------

Version a.b.c
        | | +Minor version up with only software change
        | +--Minor version up with hardware change
        +----Major version up
*/

// CONFIG1
#pragma config FOSC = INTOSC    // Oscillator Selection Bits (INTOSC oscillator: I/O function on CLKIN pin)
#pragma config WDTE = ON        // Watchdog Timer Enable (WDT disabled)
#pragma config PWRTE = ON       // Power-up Timer Enable (PWRT enabled)
#pragma config MCLRE = OFF      // MCLR Pin Function Select (MCLR/VPP pin function is digital input)
#pragma config CP = OFF         // Flash Program Memory Code Protection (Program memory code protection is disabled)
#pragma config BOREN = ON       // Brown-out Reset Enable (Brown-out Reset enabled)
#pragma config CLKOUTEN = OFF   // Clock Out Enable (CLKOUT function is disabled. I/O or oscillator function on the CLKOUT pin)
#pragma config IESO = OFF       // Internal/External Switchover Mode (Internal/External Switchover Mode is disabled)
#pragma config FCMEN = OFF      // Fail-Safe Clock Monitor Enable (Fail-Safe Clock Monitor is disabled)

// CONFIG2
#pragma config USBLSCLK = 48MHz // USB Low SPeed Clock Selection bit (System clock expects 48 MHz, FS/LS USB CLKENs divide-by is set to 8.)
#pragma config WRT = OFF        // Flash Memory Self-Write Protection (Write protection off)
#pragma config CPUDIV = CLKDIV3 // CPU System Clock Selection Bit (CPU system clock divided by 3)
#pragma config PLLMULT = 3x     // PLL Multipler Selection Bit (3x Output Frequency Selected)
#pragma config PLLEN = ENABLED  // PLL Enable Bit (3x or 4x PLL Enabled)
#pragma config STVREN = ON      // Stack Overflow/Underflow Reset Enable (Stack Overflow or Underflow will cause a Reset)
#pragma config BORV = LO        // Brown-out Reset Voltage Selection (Brown-out Reset Voltage (Vbor), low trip point selected.)
#pragma config LPBOR = OFF      // Low-Power Brown Out Reset (Low-Power BOR is disabled)
#pragma config LVP = OFF        // Low-Voltage Programming Enable (High-voltage on MCLR/VPP must be used for programming)

#include "HardwareProfile.h"
#include "osr_cdi.h"
#include "usb.h"

//------------------------------------------------------------------
//prototype
//------------------------------------------------------------------
void main(void);
void initialize_system(void);
void __interrupt() ISRCode(void);
uint8_t common_analog_digtal_conv8(uint8_t ch);

/** -----------------------------------------------------------------
 * global variable
------------------------------------------------------------------ */
volatile uint8_t	gRPM = 0;	
volatile uint8_t	gEngineState = ENGINE_STATE_STOPPED;
volatile uint8_t    gMapSelect = 0;
volatile uint8_t	gQShifterState = 0;
volatile uint8_t	gQShifterCount = 0;

/**
 * @brief Initializes the firmware and runs the foreground control loop.
 *
 * Enables interrupts, services USB/HID, updates the PVS and map selection,
 * and refreshes the status data reported to the host.
 */
void main(void) {
    uint16_t ii;
    uint8_t anresult;
    initialize_system();
    initialize_pvs_min_max();

    gpioANALOG_PU_ENABLER = ENABLE_2ND_WAVE_IGNITION;

    // Initialize interrupt setting
    INTE    = 1;		// Generic Interrupt on
    INTEDG  = 1;		// Interrupt on rising edge of INT pin
    TMR1IE  = 1;		// Timer1 interrupt on
    TMR2IE  = 1;		// Timer2 interrupt on
    TMR1ON  = 1;		// Timer1 start
    PEIE    = 1;
    GIE     = 1;

    // Main loop start
    ii=0;
    while (1) {
        // USB tasks
        usb_device_tasks();
        CLRWDT();
        hid_user_interface();
        CLRWDT();

        /*
         * Power Valve System (PVS) controller         
         */
        pvs_motor_head(gRPM, pvs_leveled_analog_data(common_analog_digtal_conv8(CHS_PVS)));

        /*
         *  Throttle position convert to map page.
         */
        switch(gCfg.tp_type){
            case TP_TYPE_1CH:
                gMapSelect = 0;
                
                if(OPT_PORT_MAPSW == gCfg.sys_opt_port) {gpioOPTPORT = 0;}
                g_status.ds.tp_pot = 0;
                break;

            case TP_TYPE_2CH:
                ANSELA	= 0b00000000;   // RA4(AN3) set to digtal input
                if(gpioSW1) {
                    gMapSelect = 1;
                    g_status.ds.tp_pot = 0xFF;
                } else {
                    gMapSelect = 0;
                    g_status.ds.tp_pot = 0;
                }
                
                if(OPT_PORT_MAPSW == gCfg.sys_opt_port) {gpioOPTPORT = (gMapSelect & 0x01);}
                break;

            default: // TP_TYPE_4CH
                ANSELA	= 0b00010000;   // RA4(AN3) set to analog input
                anresult = common_analog_digtal_conv8(CHS_THP);
                if(anresult>=gCfg.tp_threshold03)       {gMapSelect=3;}
                else if(anresult>=gCfg.tp_threshold02)  {gMapSelect=2;}
                else if(anresult>=gCfg.tp_threshold01)  {gMapSelect=1;}
                else                                    {gMapSelect=0;}
                
                // Drive map state with indicator.
                if(OPT_PORT_MAPSW == gCfg.sys_opt_port) {
                    switch(gMapSelect){
                        case 0: gpioOPTPORT = 0; break;
                        case 1: if(ii++>200) {ii=0;gpioOPTPORT=!gpioOPTPORT;} break;
                        case 2: if(ii++>100)  {ii=0;gpioOPTPORT=!gpioOPTPORT;} break;
                        case 3: gpioOPTPORT = 1; break;
                        default:gpioOPTPORT = 0;  break;
                    }
                }
                g_status.ds.tp_pot = anresult;
                break;
        }
        
        /*
         * Set status report data for PC
         */
        g_status.ds.current_map = gMapSelect;
        g_status.ds.qs_signal = (gCfg.qs_reverse_onoff_state ? !gpioSHIFTER : gpioSHIFTER);
        g_status.ds.qs_state = gQShifterState;
        CLRWDT();
        
    }
}


/**
 * @brief Handles the pickup and Timer0/Timer1/Timer2 interrupt events.
 *
 * Measures engine speed from the pickup interval, schedules ignition timing,
 * drives the thyristor gate, updates engine and quick-shifter state, and applies
 * noise filtering and rev limiting. This routine runs in interrupt context.
 */
void __interrupt() ISRCode(void) {
    static uint16_t tm1_count = 0;
    static uint16_t tm2_preset = 0;
    static uint8_t  rev_over_count = 0;
    static uint8_t  initial_analog_ignition_count = 0;

    /* ------------------------------------------------------------
     * Interruption by pickup signal
     * ------------------------------------------------------------
     * When Photo-coupler catch signal of pickup pulse (minus),
     * INTF is invoked. see, circuit diagram
     */
    if(INTF) {
        // While TMR2 and TMR0 are on, do not nothing now.
        // It might be noise of pick up signal.
        if((!TMR2ON)&&(!TMR0IE)) {

            /*
             * Pickup signal of minus is raised.
             * Stop Timer1 and store 16bit value of Timer1 for counting crank
             * rotation speed.
             */
            TMR1ON = 0;
            tm1_count = (((uint16_t)TMR1H << 8)|TMR1L);

            // Reset Timer1 and restart.
            TMR1H = 0;
            TMR1L = 0;
            TMR1ON = 1;

            // avoid 0 div.
            if(0 == tm1_count) {tm1_count = 0xFFFF;}

            // Calculate crank rotation speed.
            gRPM = (uint8_t)(gCfg.sys_numerator_for_rpm / (tm1_count>>3));

            /* Set delay time to Timer2 for ignite plug, value from gIGtbl[][].
             * The TMR2 setting values are in a table on Flash memory.
             * This value is created on the PC side and stored in flash memory via USB.
             */
            if((MAP_MAX_RPM >= gRPM) && (gRPM >= MAP_MIN_RPM)) {
                tm2_preset = gIGtbl[gMapSelect][gRPM];
                // Thyristor delay timer is set to TMR2.
                PR2   = (tm2_preset & 0x00FF);
                T2CON = (tm2_preset >> 8);
                gpioANALOG_PU_ENABLER = DISABLE_2ND_WAVE_IGNITION;
            }
            
            /*
             * (1) When the engine state is stopped, this is the first revolution
             * when the engine is started. If we digitally ignite at this time,
             * kickback will occur, so we do not ignite.
             * (2) Also, if there is a setting for analog ignition below a
             * certain number of revolutions, that processing is also done here.
             */
            if((ENGINE_STATE_STOPPED == gEngineState) ||
                    (gCfg.sys_rpm_for_an_ignition > gRPM)) {
                TMR2ON = 0;
                TMR2IF = 0;
                gpioANALOG_PU_ENABLER = ENABLE_2ND_WAVE_IGNITION;
            }
            
            /*
             * Processing of setting to perform analog ignition for a while
             * after crank rotation starts.
             */
            if(initial_analog_ignition_count > 0) {
                TMR2ON = 0;
                TMR2IF = 0;
                gpioANALOG_PU_ENABLER = ENABLE_2ND_WAVE_IGNITION;
                initial_analog_ignition_count--;
            }

            // Set Engine state flag
            gEngineState = ENGINE_STATE_STARTED;

            /*
             * Code must not be added from the start of interrupt until this point.
             * Since the timer to ignition has already been set,
             * if you do something, add it below.
             */
            // Quick shifter state-machine start
            quick_shifter();

            // Pulse signal for tachometer
            if(OPT_PORT_PULSE == gCfg.sys_opt_port) {gpioOPTPORT = 1;}
        }	
        INTF = 0;   // Reset interrupt
    }


    /* ------------------------------------------------------------
     * Timer1: Measuring crank rotational speed.
     * ------------------------------------------------------------
     * Timer1 is set by pickup signal(minus).
     * Timer1 timeout means engine stop. (or very low r.p.m.)
     */
     // Timer1 timeout means engine stop. (or very low r.p.m.)
	if(TMR1IF) { // Timer1 counter overflow.
        gpioSCRGATE = SCR_GATE_OFF;
        gEngineState = ENGINE_STATE_STOPPED;
        gRPM = 0;
        gQShifterState = QS_IDLE;
        gQShifterCount = 0;

        // Pulse signal for tachometer turn off.
        if(OPT_PORT_PULSE == gCfg.sys_opt_port) {gpioOPTPORT = 0;}

        // Initial counter for enable 2nd wave ignition.
        initial_analog_ignition_count = gCfg.count_of_an_ignition;

        /*
         * Set the positive wave pick-up signal enabler to ignite with an analog signal.
         * A second signal will instantly turn the thyristor on.
         * However, if the analog ignition count is zero, 
         * set the pick-up signal enabler for analog ignition to off to prevent ignition.
         */
        if(0==gCfg.count_of_an_ignition) {
            gpioANALOG_PU_ENABLER = DISABLE_2ND_WAVE_IGNITION;
        } else {
            gpioANALOG_PU_ENABLER = ENABLE_2ND_WAVE_IGNITION;
        }
                
		TMR1IF = 0; // Reset interrupt
	}

    /* ------------------------------------------------------------
     * Timer2: Thyristor gate open to ignite plug.
     * ------------------------------------------------------------
     * Timer2 measuring ignition timing from pick up signal(minus wave).
     * Timeout means that now it is time to ignite plug.
     */
    if(TMR2IF){
        TMR2ON = 0;

        gpioSCRGATE = SCR_GATE_ON; // Ignite plug
        if(gRPM > SCR_GATE_ON_HI_AREA) {
            __delay_us(SCR_GATE_ON_TIME_SHORT);
        } else {
            // In the low rotation range, take a longer thyristor gate time.
            // This is a measure for early TZR and RZ.
            __delay_us(SCR_GATE_ON_TIME_LONG);
        }
        if((QS_CUT_COUNTING != gQShifterState) && (rev_over_count < REV_OVER_COUNT_MAX)) {
                gpioSCRGATE = SCR_GATE_OFF;
        }

        /*
         * Rev limiter is a device fitted to an internal combustion engine
         * to restrict its maximum rotational speed.
         */
        if(gRPM > gCfg.rev_limit) {
            rev_over_count++;
        } else {
            rev_over_count = 0;
        }

        // Pulse signal for tachometer turn off.
        if(OPT_PORT_PULSE == gCfg.sys_opt_port) {gpioOPTPORT = 0;}
      
        /*
         * Burning the plug makes noise for a while. This causes malfunction,
         * so ignore it for a while.
         * Timer0 started for ignore the pulse for a while
         */
        TMR0 = gIgnoreNoiseTimer[gRPM];
        TMR0IF = 0;
        TMR0IE = 1;

        
         // Reset Timer2 interrupt
        TMR2IF = 0;
        // If noise occurs, the INTF flag will be raised. If INTF is up now,
        // ignore it.
        INTF = 0;
    }

    // Timer0 timeout event
	if(TMR0IF&&TMR0IE) {
        TMR0IF = 0;
        TMR0IE = 0;
        INTF = 0;
        
        /*
         * For a single engine, the prescaler is calculated at 256.
         * Since the rotation speed is doubled with the twin engine,
         * the prescaler is also halved to 128.
         * The reason for changing at this location is to update dynamically.
         */
        if(1==gCfg.sys_pulse_per_rotation) {
            OPTION_REGbits.PS = 0b111; // Pre-scaler Rate Select 256
        } else {
            OPTION_REGbits.PS = 0b110; // Pre-scaler Rate Select 128
        }

    }

	// For usb report
	g_status.ds.timer1 = gIGtbl[gMapSelect][gRPM];
	g_status.ds.rpm    = gRPM;
	g_status.ds.e_stop = gEngineState;
}


/**
 * @brief Reads one ADC channel and returns its 8-bit conversion result.
 *
 * @param ch ADC channel number to select.
 * @return The upper eight bits of the ADC result.
 */
uint8_t common_analog_digtal_conv8(uint8_t ch)
{
	ADCON0bits.CHS = ch;
    ADON = 1;
	__delay_us(300);    // Acquisiton delay
	GO_nDONE = 1;		// Start conversion
	while(GO_nDONE);	// Is conversion done?
	return (uint8_t)ADRESH;
    
}

/**
 * @brief Configures the clock, USB, I/O pins, ADC, and hardware timers.
 */
void initialize_system(void) {
	OSCCON = 0xFC; //3x PLL enabled from 16MHz HFINTOSC (1111 1100)
	ACTCON = 0x90; //Enable active clock tuning from USB
#ifndef __DEBUG
	while (OSCSTATbits.PLLRDY == 0); //Wait for PLL ready/locked
#endif
	WDTCONbits.WDTPS = 0b01100; // 01100 = 1:131072 (217) (Interval 4s nominal)

	user_init();
	usb_device_init();
	nWPUEN	= 0;
    WPUA	= 0b00010000;       // Weak pull up on at RA4
	TRISA	= 0b00011000;       // IN:RA3/4 OUT:RA5
	ANSELA	= 0b00010000;       // RA4(AN3) set to analog input
	PORTA	= 0b00000000;       // Reset PORTA

	TRISC	= 0b00001010;       // IN:RC1/3 OUT:RC0/2/4/5
	ANSELC	= 0b00001000;       // RC3(AN7) set to analog input
	PORTC	= 0b00000000;       // Reset PORTC

	ADCON2	= 0x0;              //  No auto-conversion trigger selected
	ADCON1	= 0b00100000;       // Clock:Fosc/32, VREF+ is VDD
    ADCON0bits.CHS = 0b00111;   // AN7 Selected
    ADCON0bits.GO = 0;          // GO off
    ADCON0bits.ADON = 0;        // ADConv enabled
    
    FVRCONbits.FVREN = 1;       // Fixed Voltage Reference is enabled
    FVRCONbits.TSEN = 1;        // Temperature Indicator is enabled
    FVRCONbits.TSRNG = 1;       // VOUT = VDD - 4VT (High Range)
    
	// Timer1 setteing
	T1CONbits.TMR1CS =0;        // 00 = Timer1 clock source is instruction clock (FOSC/4)
	T1CONbits.T1CKPS =0b11;     // Timer1 Input Clock Prescale Select bits 1:8 Prescale value
	T1CONbits.T1OSCEN=0;        // Dedicated Timer1 oscillator circuit disabled
	T1CONbits.nT1SYNC=1;        // 1 = Do not synchronize external clock input
	T1CONbits.TMR1ON =0;        // Timer1 On bit

	// Timer2 setting
	T2CON	= 0;
	PR2		= 0;
	TMR2IF	= 0;

	// Timer0 setting
	OPTION_REGbits.TMR0CS = 0;	// 0 = Internal instruction cycle clock (FOSC/4)
	OPTION_REGbits.PSA = 0;		// 0 = Pre-scaler is assigned to the Timer0 module
	OPTION_REGbits.PS = 0b111;  // Pre-scaler Rate Select bits
	T0IF = 0;
	T0IE = 0;
}

/** EOF main.c ***************************************************************/

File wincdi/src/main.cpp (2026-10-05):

/* ----------------------------------------------------------------------------
Open Source Racing CDI 'OSR-CDI' system for YAMAHA 2T motorcycle
----------------------------------------------------------------------------
Copyright(c) 2013 - 2026 Rilassaru(http://rilassaru.blog.jp/)
All rights reserved.

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
1. Redistributions of source code must retain the above copyright notice,
this list of conditions and the following disclaimer.
2. Redistributions in binary form must reproduce the above copyright notice,
this list of conditions and the following disclaimer in the documentation
and / or other materials provided with the distribution.

THIS SOFTWARE IS PROVIDED BY THE COPYRIGHT HOLDERS AND CONTRIBUTORS "AS IS" AND
ANY EXPRESS OR IMPLIED WARRANTIES, INCLUDING, BUT NOT LIMITED TO, THE IMPLIED
WARRANTIES OF MERCHANTABILITY AND FITNESS FOR A PARTICULAR PURPOSE ARE
DISCLAIMED.IN NO EVENT SHALL THE COPYRIGHT OWNER OR CONTRIBUTORS BE LIABLE FOR
ANY DIRECT, INDIRECT, INCIDENTAL, SPECIAL, EXEMPLARY, OR CONSEQUENTIAL DAMAGES
(INCLUDING, BUT NOT LIMITED TO, PROCUREMENT OF SUBSTITUTE GOODS OR SERVICES;
LOSS OF USE, DATA, OR PROFITS; OR BUSINESS INTERRUPTION) HOWEVER CAUSED AND
ON ANY THEORY OF LIABILITY, WHETHER IN CONTRACT, STRICT LIABILITY, OR TORT
(INCLUDING NEGLIGENCE OR OTHERWISE) ARISING IN ANY WAY OUT OF THE USE OF THIS
SOFTWARE, EVEN IF ADVISED OF THE POSSIBILITY OF SUCH DAMAGE.

The views and conclusions contained in the software and documentation are those
of the authors and should not be interpreted as representing official policies,
either expressed or implied, of the FreeBSD Project.
----------------------------------------------------------------------------*/

#ifdef _DEBUG
#pragma comment( lib, "mt/hidapid.lib" )
#else
#pragma comment( lib, "mt/hidapi.lib" )
#endif

#include <stdint.h>

#include <FL/Fl.H>
#include <FL/Fl_Double_Window.H>
#include <FL/Fl_Native_File_Chooser.H>
#include <FL/fl_ask.H>

#include "flscreen.h"
#include "HidDevice.h"
#include "mapdata.h"
#include <fstream>
#include <sstream>
#include <string>
#include <vector>
#include <algorithm>
#include <cctype>
#include <set>
#include <iomanip>
#include <ctime>

// define
#define WINDOW_TITLE "OSR-CDI v1.5.6"
#define FILE_DESC	"OSR-CDI\t156\n"
#define DEFAULT_FILE_NAME "osr-cdi-autosaved156.cd2"
#define STRING_BUFFER_SIZE 1024

#define MAX_UINT8 0xFF
#define MAX_UINT14 0x3FFF

#define IGN_CHART_MAX	35
#define PVS_CHART_MAX	180

#define REPEAT_TIME	(0.5)

// prototype
void repeat_callback(void*);
void msg_cb(const char* p);
int data_file_write(const char* file_name);
int data_file_read(const char* file_name);
int data_file_read_v14(const char* file_name);
int data_file_read_v15(const char* file_name);

void option_redraw();
void main_window_cb(Fl_Widget*, void*);
void resize_ignition_chart();
void device_status_ui_update(const device_id* di, const device_status* st, bool clear_flag);

// Version parsing helpers
bool ParseVersionFromProductString(const char* prodStr, int& outMajor, int& outMinor, int& outPatch, char& outRev) {
	if (!prodStr) return false;

	const char* p = strstr(prodStr, "Ver.");
	if (p) {
		p += 4; // after "Ver."
	} else {
		p = strstr(prodStr, "Ver ");
		if (p) p += 4; else return false;
	}

	while (*p == ' ') p++;

	int maj=0, min=0, pat=0;
	char rev='\0';
	// Use sscanf_s to read optional revision char
	int cnt = sscanf_s(p, "%d.%d.%d%c", &maj, &min, &pat, &rev, 1);
	if (cnt >= 3) {
		outMajor = maj;
		outMinor = min;
		outPatch = pat;
		outRev = (cnt == 4 && isalpha((unsigned char)rev)) ? rev : '\0';
		return true;
	}
	// try two-component format like 1.5
	cnt = sscanf_s(p, "%d.%d%c", &maj, &min, &rev, 1);
	if (cnt >= 2) {
		outMajor = maj; outMinor = min; outPatch = 0; outRev='\0';
		return true;
	}
	return false;
}

bool IsVersion155OrEarlier(int major, int minor, int patch) {
	int verCode = (major * 100) + (minor * 10) + patch; // e.g., 1.5.5 -> 155
	return (verCode <= 155);
}

// global
Fl_Double_Window* w;
HidDevice dev;			// CDI device connector
MapData ignMapData;
MapData pvsMapData;
char szDefaultFileName[STRING_BUFFER_SIZE];
char szCurrentFileName[STRING_BUFFER_SIZE];

/**
 * Main entry point.
 *
 * @param argc Argument count from the runtime environment.
 * @param argv Argument vector from the runtime environment.
 * @return Returns the result of Fl::run() which runs the FLTK event loop.
 */
int main(int argc, char **argv) {
	// -----------------------------------------------------------------
	// Make window
	// -----------------------------------------------------------------
	w = make_window();
	w->callback(main_window_cb);
	w->label(WINDOW_TITLE);


	
	// -----------------------------------------------------------------
	// Setup widgets
	// -----------------------------------------------------------------
	// Init Ignition table & UI
	ignMapData.SetMinMax(0, IGN_CHART_MAX);
	chart_ign->SetMapData(&ignMapData);
	chart_ign->SetChartSize(IGN_CHART_MAX, 5, 5);
	pr_tp_current->minimum(0);
	pr_tp_current->maximum(MAX_UINT8);

	// Init Power valve table & UI
	pvsMapData.SetMinMax(0, PVS_CHART_MAX);
	chart_pvs->SetMapData(&pvsMapData);
	chart_pvs->SetChartSize(PVS_CHART_MAX, 5, 10);

	// Get default path and make default file name.
	wchar_t wstr[STRING_BUFFER_SIZE];
	size_t returnvalue;
	GetTempPath(STRING_BUFFER_SIZE, wstr);
	wcstombs_s(&returnvalue, szDefaultFileName, STRING_BUFFER_SIZE, wstr, STRING_BUFFER_SIZE);
	strcat_s(szDefaultFileName, STRING_BUFFER_SIZE, DEFAULT_FILE_NAME);

	// read default .cdi
	data_file_read(szDefaultFileName);

	// Set function pointer to message 
	dev.SetMessageCallback(msg_cb);

	// default active chart is ignition map0
	btn_select_ign_map0->value(1);
	chart_ign->SetMapIndex(0);

	tabs_window->value(tab_device_infomation);
	// Now setup is done.
	w->show(argc, argv);

	// workaround
	w->size(w->w()+1, w->h()+1);

	msg->add("Started successfully.\n");
	msg->add("Waiting device connect.\n");

	Fl::add_timeout(0.1, repeat_callback);

	return(Fl::run());
}


/**
 * Window close callback.
 *
 * Saves the current data to the default file and terminates the process.
 *
 * @param widget The widget that triggered the callback (unused).
 * @param data   User data pointer (unused).
 */
/**
 * Window close callback.
 *
 * Saves the current data to the default file and terminates the process.
 *
 * @param widget The widget that triggered the callback (unused).
 * @param data   User data pointer (unused).
 */
static void main_window_cb(Fl_Widget*, void*) {
	// Save current data and perform a clean shutdown.
	data_file_write(szDefaultFileName);

	// Stop periodic callbacks to avoid touching UI after hide
	Fl::remove_timeout(repeat_callback);

	// Close device connection if open
	if (dev.isWireConnected()) {
		dev.Close();
	}

	// Hide the main window to let Fl::run() return cleanly
	if (w) {
		w->hide();
	}
}
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

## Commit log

2026-08-20 Add hardware, firmware, and WinCDI source files
    [BOM-osr-cdi15x.csv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]
2026-09-05 Some modify added to circuit.
    [BOM-osr-cdi15x.csv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]
2026-09-11 Some PCB rayout changed.
    [osr-cdi15x-CuBottom.gbr, osr-cdi15x-CuTop.gbr, osr-cdi15x-EdgeCuts.gbr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]
2026-09-13 Daily update
    [osr-cdi15x.kicad_pcb]
2026-09-27 Daily update and some bug fix.
    [BOM-osr-cdi15x.csv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]
2026-10-03 Added tool holes to gerber files
    [BOM-osr-cdi15x.csv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]
